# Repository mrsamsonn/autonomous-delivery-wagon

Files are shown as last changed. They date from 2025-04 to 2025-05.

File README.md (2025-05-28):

# 🚚 Autonomous Delivery Wagon (ADW) [In Progress]

A sidewalk-friendly autonomous delivery robot designed for scalable logistics.

<div align="center">
  Axle Installed
  Axle Installed
  Axle Installed
  Axle Installed
  <p><a href="#journal-log"> Scroll down for journal logs 📓😊!</a></p>
</div>

## 🛠️ Project Overview

The **Autonomous Delivery Wagon (ADW)** is a heavy-duty autonomous robot platform, based on a **modified garden wagon chassis**, and tailored for real-world delivery applications. Designed with affordability, modularity, and functionality in mind, ADW is engineered to carry up to **600 lbs** while navigating sidewalks and varied terrains autonomously.

tldr; designing an autonomous bot for local food delivery (ie. doordash, ubereats) by utilizing sidewalks

---

## Block Diagram

<div align="center">
  Axle Installed
</div>

---

## ⚙️ Key Features

- **Modified Commercial Wagon Base**  
  - Reinforced steel-frame platform  
  - Custom **axle replacement** for improved durability  
  - Integrated **350W high-torque motor** and servo system for controlled mobility

- **Advanced Perception Stack**  
  - Mounted **3D LiDAR** with **360° horizontal** and **90° vertical FOV** for robust environmental awareness  
  - **Mono camera** for object detection and tracking  
  - Real-time obstacle detection and path planning

- **Compute & Autonomy**  
  - Powered by **NVIDIA Jetson Nano**  
  - Running **SLAM (Simultaneous Localization and Mapping)** and **ROS (Robot Operating System)** for localization and autonomous decision-making

- **Planned Capabilities**  
  - Manual control phase (for testing and calibration)  
  - Data collection for SLAM and AI model tuning  
  - Autonomous path planning and dynamic rerouting  
  - Secure delivery logic with compartment locking

---

## 📅 Development Roadmap

> **Current Phase:** Finalizing steering for precise movement  
> **Upcoming Phase:** LiDAR Point Cloud and Mono Camera RGB data fusion

- ✅ Modify base wagon and install axle/motor system  
- ✅🔄 Integrate motor and servo components  
- ✅ Mount 3D LiDAR and mono camera  
- ✅ Building housing and electronics mount  
- ✅ Manual control setup  
- 🔄🧪 Upcoming: SLAM data collection and initial autonomy tests

---

## 📚 Tech Stack

**Hardware:**  
`Modified Wagon Frame` • `Custom Axle` • `350W Motor` • `3D LiDAR (360°x90°)` • `Mono Camera` • `Servo Steering`

**Software & Compute:**  
`NVIDIA Jetson Nano` • `ROS` • `SLAM` • `Python` • `C++`

---

## 💡 Project Goal

To create a low-cost, sidewalk-compatible autonomous delivery robot platform inspired by real-world AVs. Aiming to utilize sidewalk infastracture for logistics (ie doordash, ubereats).

---

## Journal Log

<div align="center">

### 🛞 status as of 05/28/25 [current servo not reliable 🤦‍♂️, attempting to replace with  RS380 12V steering motor ⚙️]





</div>

> ### Issue:
> - kept blowing even under low current
> - has inline fuse of 5A and board still blew at quick stall, brought inline fuse down to 3A, still blew the board
> - context, this is the second servo that blew up despite having inline fuse below rated stall current: "Stall current at locked ( 12.6V ): 8.3A"
> - should have listened to amazon 'frequently returned' warning 😅

> ### Will attempt to use RS380 12V steering motor typically used for kids electric car
> - designed and printed new holder
> - but currently experiencing tensions at specific areas due to minor measurement issues +/-1mm

<div align="center">






</div>

<div align="center">

### 🛞 status as of 05/15/25 [init ros launch script 💻]


</div>

<div align="center">

### 🛞 status as of 05/08/25 [responsive steering, but wheel alignment issue? 🛞⚙️]

new problem!!!! what's an engineering project that doesn't have issues right? 🫠

Axle Installed
Axle Installed
Axle Installed
Axle Installed

</div>

> ### Issue:
> - forward-right seems to be sliding
> ### Investigation:
> - noticed left wheel has less grip compare to right wheel
>   - further investigation shows that right wheel is slightly floating
> - noticed wagon chassis is sagging more to left side
>   - resulting to a lower left wheel and higher right wheel
> ### Attempts:
> - removing air from left wheel to lower left side and theoretically balance
>   - there was slight improvement but issue persist
> ### To Do:
> - investigate what causing chassis imbalance and attempt fix
> - dive into adding suspension
>   - might result to more complication
>   - will take more time on steering mechanism development, pushing data fusion and collection dev further.

<div align="center">

### 🛞 status as of 05/04/25 [servo and motor signal is clean 👌]

Axle Installed
Axle Installed
Axle Installed

</div>

> ### Solution:
> - Found out SDA and SCL can be enabled through device tree for Jetson Nano Pin 27/28
> - used another PCA PWM controller for servo - resulted to cleaner signals and eliminated twitching
> - but this solution met by another issue, Jetson only has two 5V pins (was being used by motor driver and pca_1) - see block diagram above for new wiring as solution

<div align="center">

### 🛞 status as of 05/02/25 [servo twitching... 🫠]

Axle Installed
Axle Installed

</div>

> ### Problem:
> Steering mech is resolved!! but currently experiencing **servo twitching**, even with no mechanical load.
> After investigation, the issue appears to stem from the **PWM signal quality** from Jetson Nano **pin 32**.
>
> ### New Findings:
> - **PWM Signal from Jetson Pin 32 (GPIO12)** appears to be a **sine-like waveform**, not a proper square wave.
>   - Observed via oscilloscope: signal is unstable and inconsistent, likely due to **software-based PWM emulation**.
> - In contrast, a PWM signal from a **PCA9685** (driven through I²C from the Jetson) is a **clean square wave**.
> - Jetson **GND is confirmed stable**, as it was used during both tests (pin 32 vs PCA).
>
> | **Pin 32 PWM Signal (Sine-Like)** | **PCA9685 PWM Signal (Clean Square Wave)** |
> |----------------------------------|--------------------------------------------|
> | <div align="center">Pin 32 PWM Signal (Sine-Like)</div> | <div align="center">PCA9685 PWM Signal (Clean Square Wave)</div> |

> ### Constraint:
> - Only one PCA9685 is available and is currently used for controlling a **brushed motor**, which runs at a different PWM frequency.
> - Jetson Nano provides only **one physical SDA/SCL pair**, limiting direct support for multiple PCA9685 boards without hardware modifications.
>
> ### Hypothesis:
> The **servo twitching** is likely caused by the poor PWM signal quality from pin 32, not wiring or voltage instability.
>
> ### Next Steps:
> 1. Test **pin 33 (GPIO13)** — a Jetson-supported PWM-capable pin that might provide a cleaner signal if properly configured through Jetson-IO.
> 2. Explore using an **I²C multiplexer (e.g., TCA9548A)** or **software I²C** to add a second PCA9685 board.
> 3. Investigate options to **clean the signal** from pin 32 using a low-pass filter or buffer (if switching pins isn't viable).
> 4. Collect and share **oscilloscope screenshots** comparing pin 32 vs PCA outputs for further debugging and validation.

<div align="center">

### 🛞 status as of 04/30/25 [steering mechanism void 🥲]

Axle Installed
Axle Installed
Axle Installed

</div>

> **Steering Mechanism Development Log**
>
> Currently facing challenges in designing and printing parts for a stable and precise steering mechanism.
>
> <div align="center">
>   
> Axle Installed
> 
> </div>
>
> **Approaches Tried:**
>
> - **Direct rotational steering**: Mounted the servo directly on the pivoting axle assembly.  
>   - *Issue:* The servo moved with the steering assembly, causing instability and limiting the range of motion.
>
> - **Lever-actuated steering using PVC arms**: Connected the servo to the wagon’s front axle with makeshift linkages.  
>   - *Issue:* This setup lacked precision and mechanical robustness.
>
> - **Current approach – Drag link steering**:
> <div align="center">
>   Axle Installed<br>
>   <em>Credits: Mekanizmalar</em>
> </div>
>
> Mounting the servo to the fixed chassis and connecting it to the steering arm via a push-pull linkage (drag link).  
> **Goal:** Achieve better mechanical control, increase range of motion, and keep the servo stationary for consistent torque application.

<div align="center">

### 🛞 status as of 04/25/25

Axle Installed

</div>

<div align="center">

### 🛞 status as of 04/17/25

Axle Installed
Axle Installed

</div>

<div align="center">

### 🛞 status as of 04/15/25

Axle Installed
Axle Installed
Axle Installed
Axle Installed

</div>

<div align="center">

### 🛞 status as of 04/03/25

Axle Installed
Axle Installed

</div>

---

## 🤝 Collaboration & Feedback

This is an ongoing solo project — open to collaboration, ideas, or advice.  
Feel free to open an issue or contact directly with feedback.

---

## 📜 License

*To be determined.*

---

## 🔔 Stay Tuned

More updates coming soon — follow commits and README changes as the project evolves!

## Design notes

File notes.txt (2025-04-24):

>>>>>>>>>>>>>>Jetson Nano<<<<<<<<<<<<<<<<<<<<<<<<<
---------------vscode w/ python---------------------
$ git clone https://github.com/JetsonHacksNano/installVSCode.git
$ cd installVSCode
./installVSCodeWithPython.sh
--------------- enable pwm pin 32 33 -------------------
Step 1: Enable PWM using busybox devmem

Run these as root (sudo su or prefix with sudo):

# Enable Pin 32 / PWM0
busybox devmem 0x700031fc 32 0x45
busybox devmem 0x6000d504 32 0x2

# Enable Pin 33 / PWM2
busybox devmem 0x70003248 32 0x46
busybox devmem 0x6000d100 32 0x00

Step 2: Control PWM via sysfs

cd /sys/devices/7000a000.pwm/pwm/pwmchip0
echo 0 > export  # For PWM0 (Pin 32) — use 2 for PWM2 (Pin 33)
cd pwm0
echo 20000000 > period        # 20ms period (50Hz)
echo 1500000 > duty_cycle     # 1.5ms pulse width (7.5% duty cycle)
echo 1 > enable

Step 3: Make Persistent with Crontab

To avoid running these commands manually after each reboot:

sudo crontab -e

Then add at the bottom:

@reboot sleep 10 && busybox devmem 0x700031fc 32 0x45 && busybox devmem 0x6000d504 32 0x2
@reboot sleep 10 && busybox devmem 0x70003248 32 0x46 && busybox devmem 0x6000d100 32 0x00

This ensures the pins are reconfigured correctly ~10 seconds after boot.
🧩 Optional: Add to Script

(optional) shell script instead of crontab:

#!/bin/bash
# pwm_init.sh
busybox devmem 0x700031fc 32 0x45
busybox devmem 0x6000d504 32 0x2
busybox devmem 0x70003248 32 0x46
busybox devmem 0x6000d100 32 0x00

Then place it in /etc/rc.local or systemd service if needed.

>>>>>>>>>>>>>>>>>>>>>>>>>>> ROS <<<<<<<<<<<<<<<<<<<<<<<<<<<
Step 1: Install ROS Melodic

Run each command one at a time:

sudo sh -c 'echo "deb http://packages.ros.org/ros/ubuntu bionic main" > /etc/apt/sources.list.d/ros-latest.list'

sudo apt-key adv --keyserver 'hkp://keyserver.ubuntu.com:80' --recv-key C1CF6E31E6BADE8868B172B4F42ED6FBAB17C654

sudo apt update
sudo apt install ros-melodic-desktop-full -y

Step 2: Environment Setup

Add ROS to your bash startup:

echo "source /opt/ros/melodic/setup.bash" >> ~/.bashrc
source ~/.bashrc

Then install ROS tools:

sudo apt install python-rosdep python-rosinstall python-rosinstall-generator python-wstool build-essential -y

Initialize rosdep:

sudo rosdep init
rosdep update

Step 3: Create and Build Your Catkin Workspace

mkdir -p ~/catkin_ws/src
cd ~/catkin_ws/
catkin_make

Add the workspace to your bash profile:

echo "source ~/catkin_ws/devel/setup.bash" >> ~/.bashrc
source ~/.bashrc

---------------------Unitree LiDAR 4D L1 Setup-------------------------
Step 4: Clone the unilidar_sdk Repository

Navigate to the src directory in your catkin_ws:

cd ~/catkin_ws/src

Clone the unilidar_sdk repository:

git clone https://github.com/unitreerobotics/unilidar_sdk.git

[make sure to do sudo rm -rf ~unilidar_sdk_ros2]

Step 5: Install Dependencies

Before we can build the package, make sure the necessary dependencies are installed:

sudo apt update
sudo apt install ros-melodic-pcl-ros libpcl-dev libyaml-cpp-dev

Step 6: Build the Workspace

Go back to the root of your catkin_ws and build everything:

cd ~/catkin_ws
catkin_make

Source the setup file to set up the environment:

source devel/setup.bash

You can add source ~/catkin_ws/devel/setup.bash to your .bashrc to automatically source it every time.

Step 7: Configure the LiDAR

Next, we'll configure the unitree_lidar_ros package by specifying the correct port for the LiDAR:

    Find the correct serial port where the LiDAR is connected:

ls /dev/ttyUSB*

This will return the serial device for your LiDAR, such as /dev/ttyUSB0 or similar.

Modify the config.yaml file to specify the correct port. Open it using your editor (nano, vim, etc.):

nano ~/catkin_ws/src/unilidar_sdk/unitree_lidar_ros/config/config.yaml

[jetson@jetson-desktop:~/catkin_ws/src/unilidar_sdk/unitree_lidar_ros/src/unitree_lidar_ros/config$ nano config.yaml]

Modify the port value to match your LiDAR's serial port:

port: "/dev/ttyUSB0"  # Replace with your actual port

Save and close the file.

 Step 8: Run the Unitree LiDAR Driver

You’re almost there! Now, you can launch the LiDAR driver:

[reboot before launch]

[imu error fix] You can change the Fixed Frame to the imu frame unilidar_imu, so that you can view the IMU quaternion vector:

roslaunch unitree_lidar_ros run.launch
---------------------------------------------
----**If permission denied at launch**---
1. Verify and Ensure Proper Permissions for the Serial Device

    Identify your device:

    Run the following command to check your serial device:

ls /dev/ttyUSB*

This will show something like /dev/ttyUSB0, /dev/ttyUSB1, etc.

Check permissions:

Verify the permissions on the identified serial device (/dev/ttyUSB0 or others):

ls -l /dev/ttyUSB0

The output should look like this:

crw-rw---- 1 root dialout 188, 0 <timestamp> /dev/ttyUSB0

If the device is not assigned to the dialout group or has incorrect permissions, run:

    sudo chown root:dialout /dev/ttyUSB0
    sudo chmod 660 /dev/ttyUSB0

    After doing this, check again to make sure the serial port has the correct permissions.

    Reboot the system:

    If you made changes to the group or permissions, reboot your system to ensure the changes persist.

2. Confirm the dialout Group is Applied

Make sure that your user is still part of the dialout group:

groups jetson

This should list dialout as one of the groups. If it's not listed, add your user to the group again:

sudo usermod -aG dialout $USER

Then, log out and log back in, or reboot the system.
-------------------------------------------------
-------------------------------------------------

---------------------- Camera Node -------------------------
✅ 1. Camera Node with Image Pipeline (C920 Mono Camera)

Install and run the ROS camera node:

sudo apt install ros-melodic-usb-cam
******
Make sure the ROS master is running:

roscore

Environment:
Run these in each terminal before launching ROS nodes:

source /opt/ros/melodic/setup.bash
source ~/catkin_ws/devel/setup.bash

You can also add them to your .bashrc:

echo "source /opt/ros/melodic/setup.bash" >> ~/.bashrc
echo "source ~/catkin_ws/devel/setup.bash" >> ~/.bashrc
source ~/.bashrc

3. Check if the master URI is set

Make sure ROS_MASTER_URI is pointing to the correct machine (usually localhost if everything is on Jetson Nano):

export ROS_MASTER_URI=http://localhost:11311
export ROS_HOSTNAME=localhost

********
Then run:

rosrun usb_cam usb_cam_node

Check image stream:

rqt_image_view

Make sure the topic (usually /usb_cam/image_raw) is available.

Init Camera Node Steps:
1. If you're trying to stream the video into ROS (e.g., for a robot or CV pipeline):

Make sure your roscore is running (that previous error said it wasn’t):

roscore

Then in a new terminal:

rosrun usb_cam usb_cam_node

And you can view the video with:

rqt_image_view

    If usb_cam is not installed, you can install it with:

sudo apt install ros-melodic-usb-cam

---------------------- LiDAR and Camera Fusion --------------------
make sure roscore is running
then do source ~/.bashrc
rosrun and roslaunch camera and lidar
rostopic echo /unilidar/cloud

prereq:
sudo apt install ros-melodic-cv-bridge ros-melodic-image-transport

>>>>>>>>>>>>>>>> Mono Camera [c920] <<<<<<<<<<<<<<<<<<<<<

view: 
gst-launch-1.0 v4l2src device=/dev/video0 ! image/jpeg, width=1920, height=1080, framerate=30/1 ! jpegdec ! videoconvert ! autovideosink

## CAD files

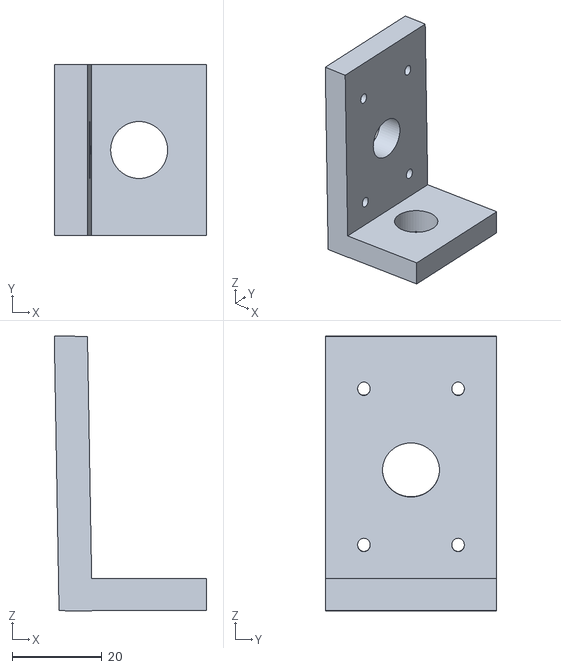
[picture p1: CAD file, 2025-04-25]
stl-files/steer-connector-v5.stl
34.0 x 38.1 x 61.4

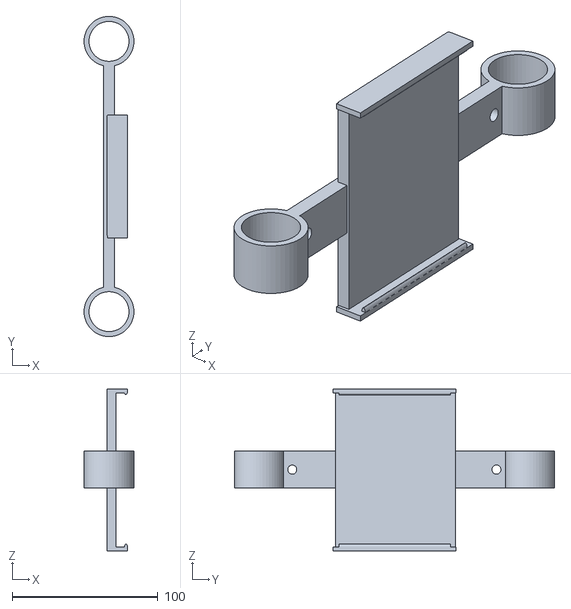
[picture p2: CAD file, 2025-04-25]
stl-files/jetson-nano-custom-pvc-holder.stl
34.3 x 219.9 x 111.2

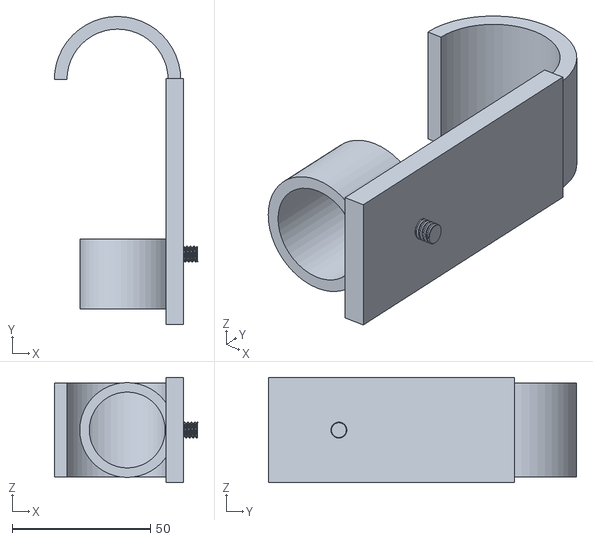
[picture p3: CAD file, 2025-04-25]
stl-files/camera-holder(1).stl
51.8 x 111.4 x 38.1

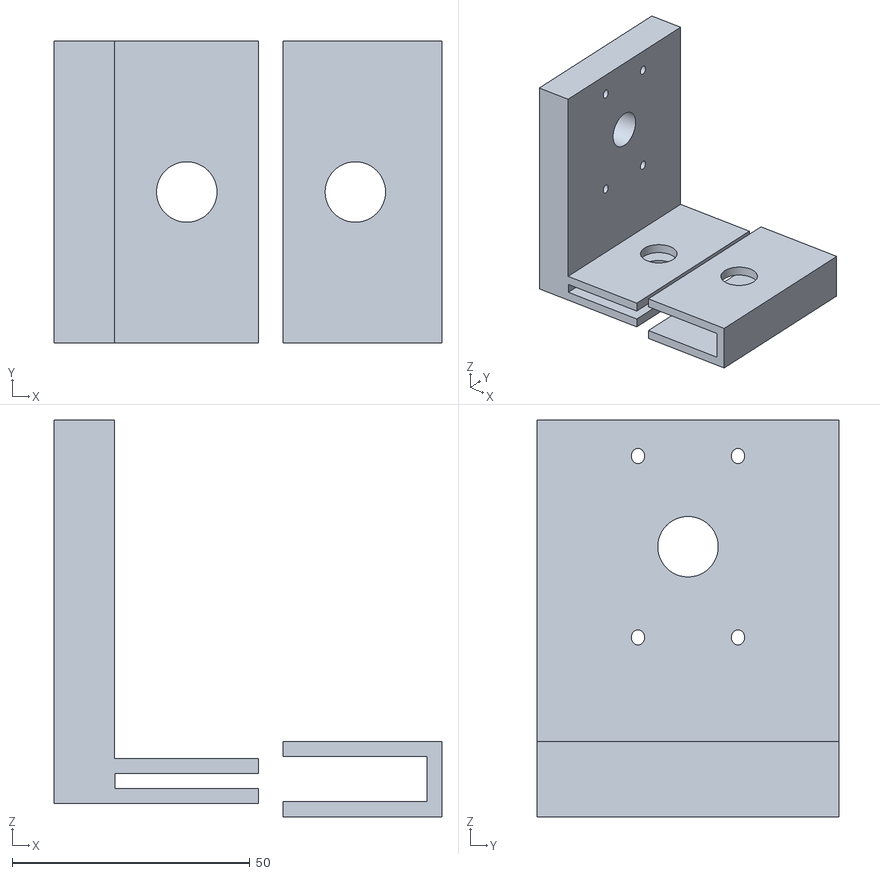
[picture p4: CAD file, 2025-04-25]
stl-files/servo-connector(1).stl
81.5 x 63.5 x 83.3

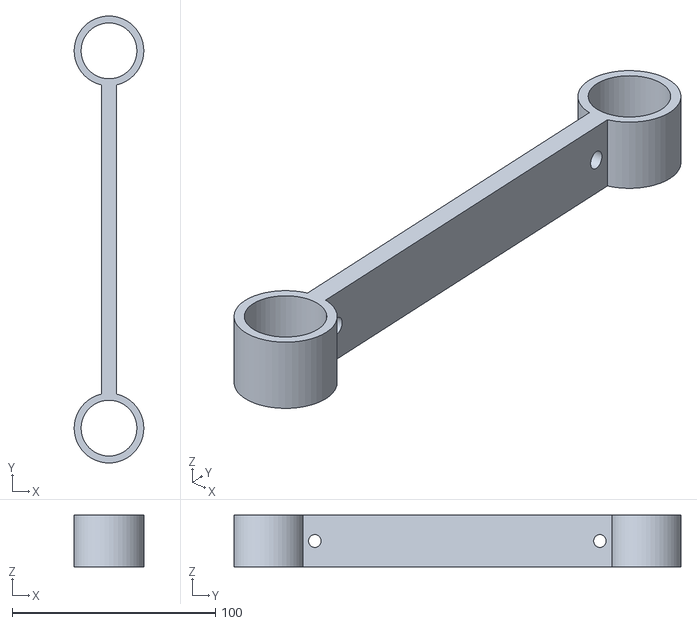
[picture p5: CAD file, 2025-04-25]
stl-files/Copy of bus-holder.stl
34.3 x 219.9 x 25.4

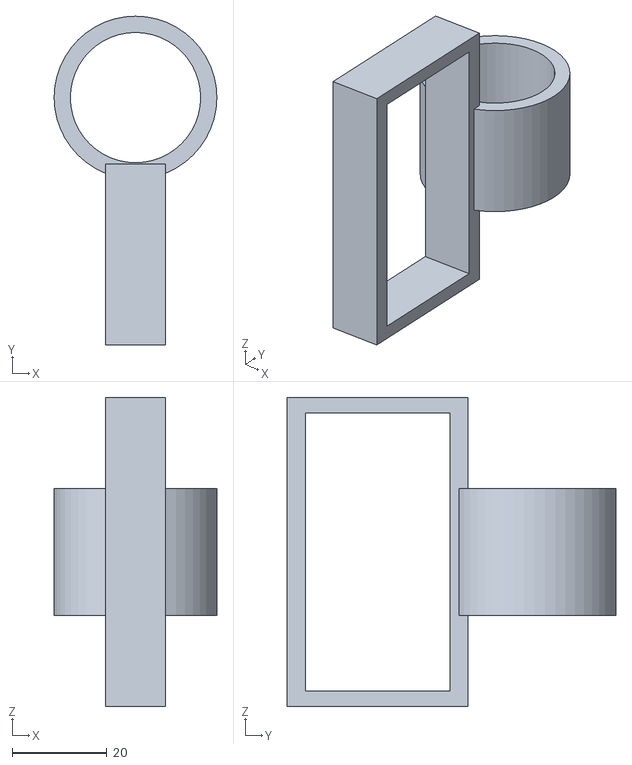
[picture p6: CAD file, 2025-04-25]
stl-files/battery-reader-holder(3).stl
34.3 x 69.2 x 65.1

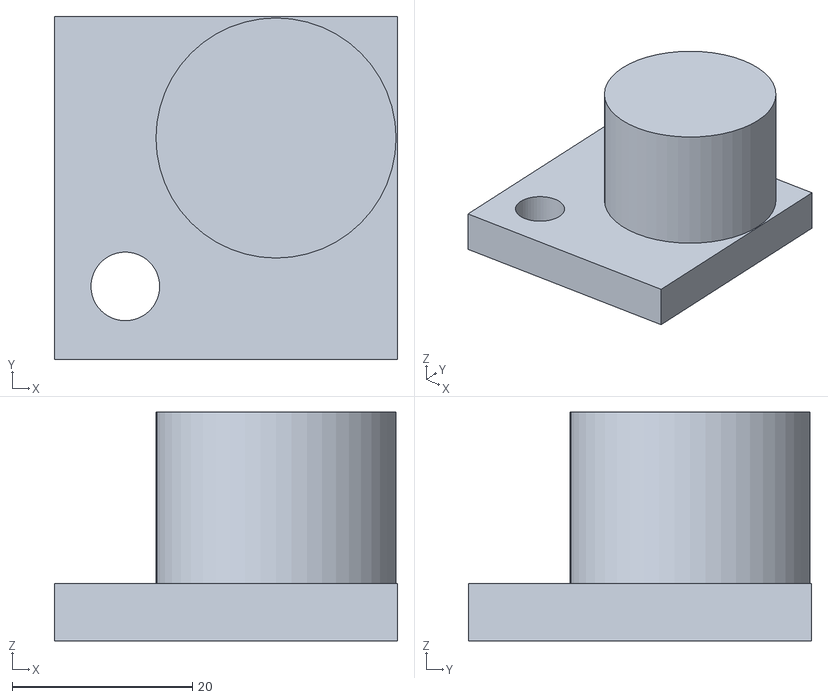
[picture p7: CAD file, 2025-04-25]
stl-files/pvc-holder(1).stl
38.1 x 38.1 x 25.4

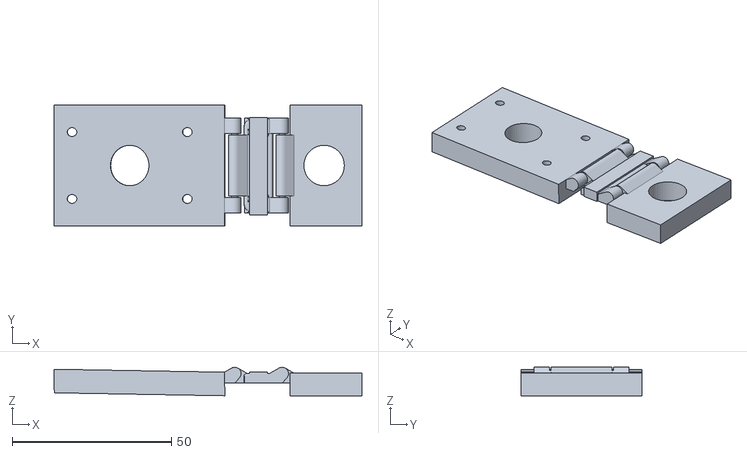
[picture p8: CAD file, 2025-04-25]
stl-files/steer-connector-v4(1).stl
96.8 x 38.1 x 8.97

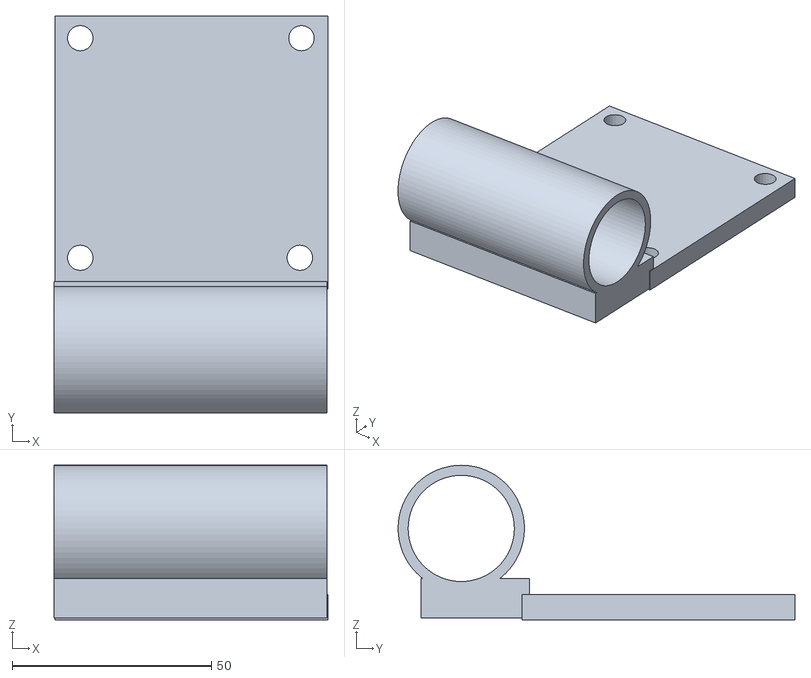
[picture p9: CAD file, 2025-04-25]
stl-files/4 pvc.stl
68.8 x 99.7 x 38.8

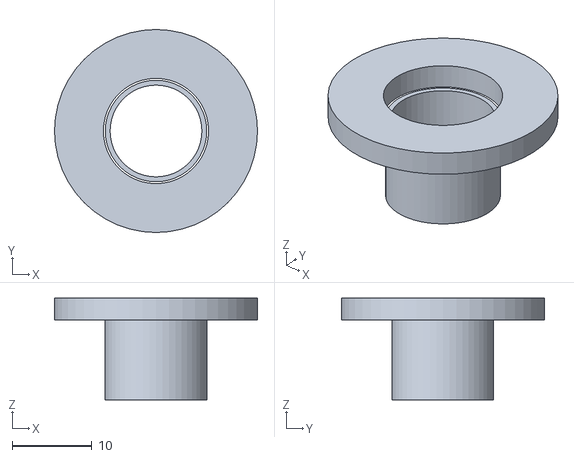
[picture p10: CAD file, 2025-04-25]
stl-files/servo-hole(1).stl
25.4 x 25.4 x 12.7

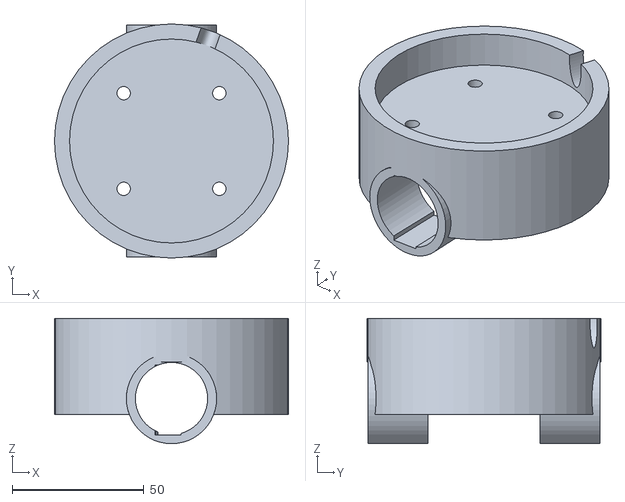
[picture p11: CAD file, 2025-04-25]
stl-files/unitree-4D-Lidar-L1-holder-backup(1).stl
88.9 x 88.9 x 47.6

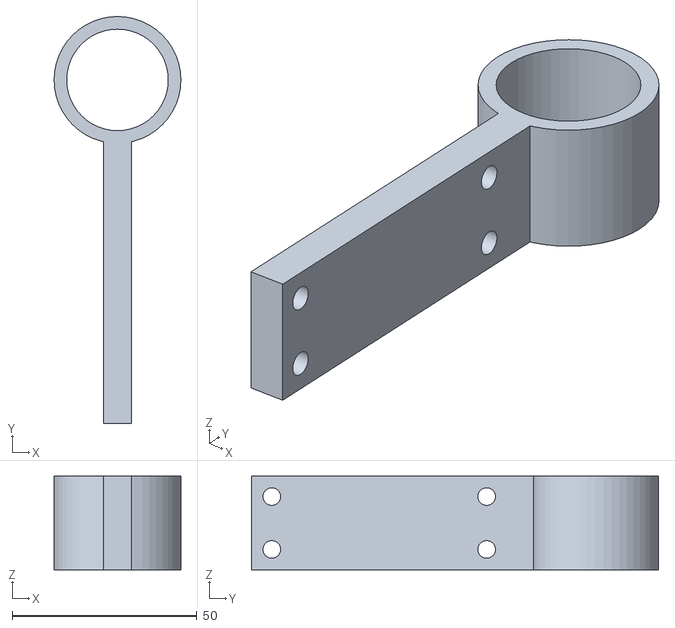
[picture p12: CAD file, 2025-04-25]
stl-files/pwm-controller-holder(1).stl
34.3 x 110.0 x 25.4

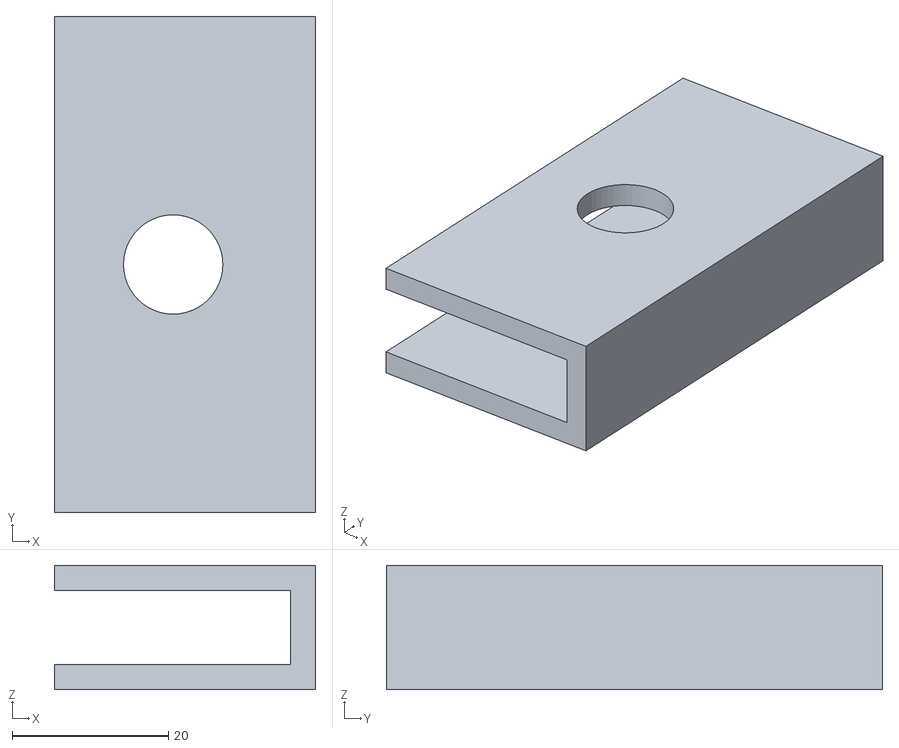
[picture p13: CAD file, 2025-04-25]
stl-files/servo-connector-clip(1).stl
33.4 x 63.5 x 15.9

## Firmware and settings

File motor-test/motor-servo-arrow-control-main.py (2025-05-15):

import os
import time
import curses
import busio
import math
from board import SCL, SDA
from adafruit_pca9685 import PCA9685

### --- PCA9685 Setup for Motor --- ###
i2c = busio.I2C(SCL, SDA)
pca = PCA9685(i2c)
pca.frequency = 1000  # 1kHz PWM
motor_speed = 0.15  # 0.0 to 1.0

def stop_motor():
    pca.channels[0].duty_cycle = 0
    pca.channels[1].duty_cycle = 0

def move_forward():
    pca.channels[0].duty_cycle = 0
    pca.channels[1].duty_cycle = int(0xFFFF * motor_speed)

def move_backward():
    pca.channels[0].duty_cycle = int(0xFFFF * motor_speed)
    pca.channels[1].duty_cycle = 0

### --- Jetson PWM Setup for Servo --- ###
PWM_BASE = "/sys/devices/7000a000.pwm/pwm/pwmchip0"
PWM0_PATH = os.path.join(PWM_BASE, "pwm0")

PERIOD_NS = 20000000
# Adjustable center pulse width (in nanoseconds)
CENTER_NS = 1600000  # Default center (you can tweak this)

# Range to stay away from hard limits (in microseconds)
RANGE_US = 600  # ±300 μs → 1200–2000 μs

#range: 500–2500μs

# Calculate left/right relative to center
LEFT_NS  = CENTER_NS - (RANGE_US * 1000) // 2
RIGHT_NS = CENTER_NS + (RANGE_US * 1000) // 2

print(LEFT_NS)
print(RIGHT_NS)

def export_pwm(channel):
    try:
        with open(os.path.join(PWM_BASE, "export"), "w") as f:
            f.write(str(channel))
        time.sleep(0.1)
    except Exception:
        pass  # Already exported

def set_pwm(path, period, duty, enable):
    with open(os.path.join(path, "period"), "w") as f:
        f.write(str(period))
    with open(os.path.join(path, "duty_cycle"), "w") as f:
        f.write(str(duty))
    with open(os.path.join(path, "enable"), "w") as f:
        f.write(str(enable))

def smooth_move(target_ns, max_steps=200, delay=0.01):
    """Smooth and continuous servo movement."""
    current_ns = get_current_pwm_value()
    current_ns = max(1000000, min(current_ns, 2000000))  # stay in safe range

    distance = abs(target_ns - current_ns)
    steps = min(max_steps, int(distance / 5))  # more steps for bigger moves

    for i in range(1, steps + 1):
        t = i / steps
        # Cosine easing
        eased_t = 0.5 * (1 - math.cos(math.pi * t))
        interp_ns = current_ns + (target_ns - current_ns) * eased_t
        set_pwm(PWM0_PATH, PERIOD_NS, int(interp_ns), 1)
        time.sleep(delay)

    set_pwm(PWM0_PATH, PERIOD_NS, target_ns, 1)
    set_current_pwm_value(target_ns)

# You need to maintain current PWM value globally
current_pwm_value = CENTER_NS

def get_current_pwm_value():
    global current_pwm_value
    return current_pwm_value

def set_current_pwm_value(value):
    global current_pwm_value
    current_pwm_value = value

def move_left():
    smooth_move(LEFT_NS)

def move_right():
    smooth_move(RIGHT_NS)

def center_servo():
    smooth_move(CENTER_NS)

def stop_servo():
    smooth_move(CENTER_NS)
    time.sleep(0.1)
    set_pwm(PWM0_PATH, PERIOD_NS, CENTER_NS, 0)

### --- Combined Main Control --- ###
def main(stdscr):
    curses.curs_set(0)
    stdscr.nodelay(1)
    stdscr.clear()
    stdscr.addstr(0, 0, "↑↓: Motor | ←→: Steer | SPACE: Center | ESC: Exit")
    stdscr.refresh()

    motor_direction = None
    servo_direction = None

    center_servo()

    while True:
        key = stdscr.getch()

        if key == curses.KEY_UP:
            if motor_direction != "forward":
                move_forward()
                motor_direction = "forward"
                stdscr.addstr(1, 0, "Motor: Forward     ")

        elif key == curses.KEY_DOWN:
            if motor_direction != "backward":
                move_backward()
                motor_direction = "backward"
                stdscr.addstr(1, 0, "Motor: Backward    ")

        elif key == curses.KEY_LEFT:
            if servo_direction != "left":
                move_left()
                servo_direction = "left"
                stdscr.addstr(2, 0, "Steering: Left     ")

        elif key == curses.KEY_RIGHT:
            if servo_direction != "right":
                move_right()
                servo_direction = "right"
                stdscr.addstr(2, 0, "Steering: Right    ")

        elif key == ord(' '):  # Spacebar to center
            center_servo()
            servo_direction = "center"
            stdscr.addstr(2, 0, "Steering: Centered ")

        elif key == 27:  # ESC to stop all
            stop_motor()
            center_servo()
            time.sleep(1)
            stop_servo()
            stdscr.addstr(3, 0, "Stopped. Exiting... ")
            stdscr.refresh()
            break

        elif key == -1:
            if motor_direction is not None:
                stop_motor()
                motor_direction = None
                stdscr.addstr(1, 0, "Motor: Stopped     ")

        stdscr.refresh()
        time.sleep(0.1)

### --- Init and Launch --- ###
if __name__ == "__main__":
    export_pwm(0)
    center_servo()
    print("Motors and servo ready. Launching UI...")
    time.sleep(1)
    curses.wrapper(main)
    stop_servo()
    print("Exited. Servo disabled.")

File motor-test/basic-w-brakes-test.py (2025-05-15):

import time
import curses
import busio
import board
from adafruit_pca9685 import PCA9685

### --- Setup Motor PCA9685 (SCL, SDA) --- ###
i2c_motor = busio.I2C(board.SCL, board.SDA)
pca_motor = PCA9685(i2c_motor)
pca_motor.frequency = 1000  # 1kHz for motor
motor_speed = 0.15  # Adjust as needed

def stop_motor():
    pca_motor.channels[0].duty_cycle = 0
    pca_motor.channels[1].duty_cycle = 0

def move_forward():
    pca_motor.channels[0].duty_cycle = 0
    pca_motor.channels[1].duty_cycle = int(0xFFFF * motor_speed)

def move_backward():
    pca_motor.channels[0].duty_cycle = int(0xFFFF * motor_speed)
    pca_motor.channels[1].duty_cycle = 0

### --- Setup Servo PCA9685 (SCL_1, SDA_1) --- ###
i2c_servo = busio.I2C(board.SCL_1, board.SDA_1)
pca_servo = PCA9685(i2c_servo)
pca_servo.frequency = 50  # 50Hz for servo (20ms)

def pulse_width_to_duty_cycle(ms):
    return int((ms / 20.0) * 0xFFFF)

# Define pulse width limits
MIN_TURN_MS = 1.3
MAX_TURN_MS = 1.9
CENTER_MS = 1.55
TURN_STEP = 0.1

current_servo_ms = CENTER_MS

def update_servo(ms_value):
    global current_servo_ms
    current_servo_ms = max(MIN_TURN_MS, min(MAX_TURN_MS, ms_value))
    pca_servo.channels[0].duty_cycle = pulse_width_to_duty_cycle(current_servo_ms)

def move_left():
    update_servo(current_servo_ms - TURN_STEP)

def move_right():
    update_servo(current_servo_ms + TURN_STEP)

def center_servo(last_direction=None):
    global current_servo_ms
    if last_direction == "right":
        overshoot = 1.4
    elif last_direction == "left":
        overshoot = 1.7
    else:
        overshoot = CENTER_MS

    pca_servo.channels[0].duty_cycle = pulse_width_to_duty_cycle(overshoot)
    time.sleep(0.75)  # Give time for overshoot
    pca_servo.channels[0].duty_cycle = pulse_width_to_duty_cycle(CENTER_MS)
    current_servo_ms = CENTER_MS

def stop_motor():
    # Dynamic braking: both channels ON
    pca_motor.channels[0].duty_cycle = 0xFFFF
    pca_motor.channels[1].duty_cycle = 0xFFFF


### --- Main Control Loop --- ###
def main(stdscr):
    curses.curs_set(0)
    stdscr.nodelay(1)
    stdscr.clear()
    stdscr.addstr(0, 0, "↑↓: Motor | ←→: Steer | SPACE: Center | ESC: Exit")

    motor_direction = None
    servo_direction = None
    center_servo()

    while True:
        key = stdscr.getch()

        # --- Motor Controls ---
        if key == curses.KEY_UP:
            if motor_direction != "forward":
                move_forward()
                motor_direction = "forward"
                stdscr.addstr(2, 0, "Motor: Forward      ")

        elif key == curses.KEY_DOWN:
            if motor_direction != "backward":
                move_backward()
                motor_direction = "backward"
                stdscr.addstr(2, 0, "Motor: Backward     ")

        elif key == -1:
            if motor_direction is not None:
                stop_motor()
                motor_direction = None
                stdscr.addstr(2, 0, "Motor: Stopped      ")

        # --- Servo Controls ---
        elif key == curses.KEY_LEFT:
            move_left()
            servo_direction = "left"
            stdscr.addstr(3, 0, f"Steering: Left ({current_servo_ms:.1f}ms)   ")

        elif key == curses.KEY_RIGHT:
            move_right()
            servo_direction = "right"
            stdscr.addstr(3, 0, f"Steering: Right ({current_servo_ms:.1f}ms)  ")

        elif key == ord(' '):  # Space to center
            center_servo(servo_direction)
            servo_direction = "center"
            stdscr.addstr(3, 0, "Steering: Centered     ")

        # --- Exit ---
        elif key == 27:  # ESC
            stop_motor()
            center_servo()
            stop_servo()
            stdscr.addstr(5, 0, "Exiting...           ")
            stdscr.refresh()
            break

        stdscr.refresh()
        time.sleep(0.1)

### --- Launch --- ###
if __name__ == "__main__":
    print("Initializing motor and servo...")
    center_servo()  # Use default overshoot logic
    time.sleep(1)
    curses.wrapper(main)
    stop_motor()
    stop_servo()
    print("Exited. Motor and servo disabled.")

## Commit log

2025-04-23 servo no pca testing
2025-04-23 servo return to center before exit
2025-04-24 motor-testing: servo/brushed combo
2025-05-15 basic motor test iterations
2025-05-15 launch - flipped lidar tf - z axis
